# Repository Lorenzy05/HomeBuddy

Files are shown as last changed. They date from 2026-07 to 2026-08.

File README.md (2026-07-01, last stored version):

# 🏠 HomeBuddy - Home Service Robot · Ultimate Project Plan

> **Version**: v1.2
> **Date**: 2026-07-01
> **Updates**: Procurement via purchase or 3D printing; simplified power architecture; removed mobile App control; restructured implementation into task modules.

---

## 📖 Table of Contents

1. [Project Overview](#1-project-overview)
2. [System Architecture](#2-system-architecture)
3. [Hardware List](#3-hardware-list)
4. [Wiring Scheme](#4-wiring-scheme)
5. [Communication Protocol](#5-communication-protocol)
6. [Control Methods](#6-control-methods)
7. [Function Modules](#7-function-modules)
8. [Implementation Tasks](#8-implementation-tasks)
9. [Acceptance Criteria](#9-acceptance-criteria)
10. [Risks & Mitigations](#10-risks--mitigations)
11. [Future Extensions](#11-future-extensions)

## 1. Project Overview

| Item | Description |
|---|---|
| 🏠 Project Name | **HomeBuddy** |
| 🎯 Positioning | Home intelligent service robot |
| ✨ Core Functions | 🗣️ Voice Chat · 👁️ Face Following · 🎮 Remote Control · 📦 Auto Delivery |
| 🧠 Architecture | Raspberry Pi (Brain) + ESP32-S3 (Executor) |
| 🎛️ Control Methods | Voice 🎤 + Remote 📟 (Dual Mode) |

### 🧭 Design Principles

| Principle | Description |
|---|---|
| 🔹 Separation of Concerns | Raspberry Pi handles AI, ESP32 handles hardware |
| 🔹 Wired Communication | UART serial, stable and reliable |
| 🔹 Dual Control | Voice + Remote, switch anytime |
| 🔹 Safety First | Remote can take over anytime for emergency stop |
| 🔹 Plug & Play | All audio devices are USB, no extra drivers needed |

## 2. System Architecture

```
┌─────────────────────────────────────────────────────────────────┐
│                      👤 User Interaction Layer                  │
│  ┌─────────────────────┐  ┌─────────────────────┐            │
│  │      🎤 Voice       │  │     📟 Remote       │            │
│  │     Control         │  │     Control         │            │
│  │  (Natural Language) │  │  (IR Physical Keys) │            │
│  └──────────┬──────────┘  └──────────┬──────────┘            │
│             └────────────┬────────────┘                       │
└──────────────────────────┼────────────────────────────────────┘
                           │
┌──────────────────────────┼────────────────────────────────────┐
│                          ▼                                     │
│              🧠 Raspberry Pi 4B (Brain / 8GB)                 │
│  ┌────────────────────────────────────────────────────────┐   │
│  │  📦 Software Functions:                               │   │
│  │  🎤 Vosk STT (Speech Recognition)                    │   │
│  │  🔊 Edge-TTS (Speech Synthesis)                      │   │
│  │  🤖 Ollama (Local LLM / Gemma 2B)                   │   │
│  │  👁️ MediaPipe (Face Detection)                       │   │
│  │  🎯 Face Following Algorithm (PID Control)           │   │
│  │  🔄 Mode Management (Remote / Follow / Delivery)     │   │
│  └──────────────────┬─────────────────────────────────────┘   │
│                     │ 🔗 UART Serial (GPIO14/15)               │
│                     │ 📨 Command Protocol                     │
│                     │ 🔋 Power: Power Bank (USB-C)            │
└─────────────────────┼────────────────────────────────────────┘
                      │
┌─────────────────────┼────────────────────────────────────────┐
│                     ▼                                         │
│            ⚙️ ESP32-S3 (Executor / Sub-brain)                 │
│  ┌────────────────────────────────────────────────────────┐   │
│  │  🔧 Hardware Control:                                 │   │
│  │  🚗 L298N → DC Motors ×2 (Wheels)                    │   │
│  │  🦾 SG90 Servos ×3-4 (Pan-Tilt / Tray / Head)        │   │
│  │  🧭 MPU6050 (IMU / Anti-spill Compensation)          │   │
│  │  📟 HX1838 (IR Remote Receiver)                      │   │
│  │  🖥️ OLED SSD1306 (Face/Expression Display)           │   │
│  │  💡 NeoPixel (RGB Status LED)                        │   │
│  │  🔋 ADC (Battery Monitoring)                         │   │
│  └────────────────────────────────────────────────────────┘   │
└─────────────────────────────────────────────────────────────────┘
```

### 🎵 Audio Solution

```
┌─────────────────────────────────────────────────────┐
│           Raspberry Pi USB Audio Solution           │
│  ┌───────────────┐    ┌───────────────┐           │
│  │  🎤 STJF USB  │    │  🔊 Dual      │           │
│  │  Microphone   │    │  USB Speaker  │           │
│  │  (Audio In)   │    │  (Audio Out)  │           │
│  └───────┬───────┘    └───────┬───────┘           │
│          │                    │                    │
│          └────────┬───────────┘                    │
│                   ▼                                │
│          ┌─────────────────┐                       │
│          │  Raspberry Pi   │                       │
│          │  USB Ports      │                       │
│          │  (Plug & Play)  │                       │
│          └─────────────────┘                       │
└─────────────────────────────────────────────────────┘
```

## 3. Hardware List

### ✅ Already Owned

| Component | Model | Qty | Status |
|---|---|:---:|:---:|
| 🧠 Main Board 1 | Raspberry Pi 4B 8GB + 128GB | 1 | ✅ Owned |
| ⚙️ Main Board 2 | ESP32-S3 DevKit | 1 | ✅ Owned |
| 📷 Camera | USB Webcam 1080P | 1 | ✅ Owned |
| 🎤 Microphone | STJF mini USB Microphone | 1 | ✅ Owned |
| 🔊 Speaker | Dual Horn USB Speaker | 1 | ✅ Owned |
| 🔋 Power Bank | Power Bank (USB-C Output) | 1 | ✅ Owned |
| 🦾 Servo | SG90 9g | 3-4 | ✅ Owned |
| 🧭 IMU | MPU6050 | 1 | ✅ Owned |
| 🚗 Motor Driver | L298N | 1 | ✅ Owned |
| 🖥️ Display | OLED SSD1306 128x64 | 1 | ✅ Owned |
| 💡 RGB LED | NeoPixel | 1 | ✅ Owned |
| 📟 IR Receiver | HX1838 + Remote Control | 1 | ✅ Owned |
| 🎤 Mic (spare) | INMP441 | 1 | ⚠️ Spare |
| 🔊 Amp (spare) | MAX98357A | 1 | ⚠️ Spare |

### 🆕 To Purchase (Buy or 3D Print)

| # | Item | Spec | Qty | Budget | Notes |
|:-:|---|---|:---:|:---:|---|
| 1 | 🛞 Chassis | 30×25cm Acrylic / 3D Printed | 1 | ¥20-40 | Buy or self-print |
| 2 | 🏎️ Rubber Wheels | Diameter 8-10cm | 2 | ¥60-100 | Purchase |
| 3 | 🔄 Caster Wheel | Metal bracket | 1 | ¥15-20 | Purchase |
| 4 | 🔋 LiPo Battery | 12V 3S 18650 (with protection) | 1 | ¥120-180 | Only for L298N + motors |
| 5 | 🔩 Standoff + Screw Kit | M2.5/M3 various lengths | 1 set | ¥20-30 | Purchase |
| 6 | 📡 Jumper Wire Set | M/M, M/F, F/F | 1 set | ¥15 | Purchase |
| 7 | 🔌 USB Extension Cable | Male to Female, 1m | 1 | ¥10 | Flexible camera placement |
| 8 | 🎗️ Cable Ties + Nano Tape | Assorted | 1 pack | ¥10 | Purchase |
| 9 | 🖨️ 3D Printing Filament | PLA / PETG (if self-printing) | 1 spool | ¥60-100 | Optional |

**Total Budget: ~¥330-555**

## 4. Wiring Scheme

### 4.1 🌲 Raspberry Pi Side

| Port | → Connected To | Description |
|---|---|---|
| USB-A | 📷 USB Webcam | Video Input |
| USB-A | 🎤 STJF USB Microphone | Audio Input (Speech Recognition) |
| USB-A | 🔊 Dual USB Speaker | Audio Output (TTS) |
| USB-C | 🔋 Power Bank | Raspberry Pi Power |
| GPIO14 (TX) | ⚙️ ESP32 RX | Serial TX |
| GPIO15 (RX) | ⚙️ ESP32 TX | Serial RX |
| GND | ⚙️ ESP32 GND | Common Ground |

### 4.2 ⚙️ ESP32 Side

| Pin | → Connected To | Description |
|-----|---|---|
| UART RX | 🌲 Raspberry Pi TX | Receive Commands |
| UART TX | 🌲 Raspberry Pi RX | Send Feedback |
| GND | 🌲 Raspberry Pi GND | Common Ground |
| GPIO4 | 🚗 L298N IN1 | Left Motor A |
| GPIO5 | 🚗 L298N IN2 | Left Motor B |
| GPIO6 | 🚗 L298N IN3 | Right Motor A |
| GPIO7 | 🚗 L298N IN4 | Right Motor B |
| GPIO8 (PWM) | 🦾 SG90 Servo 1 | Pan (Left/Right) |
| GPIO9 (PWM) | 🦾 SG90 Servo 2 | Tilt (Up/Down) |
| GPIO10 (PWM) | 🦾 SG90 Servo 3 | Tray Compensation |
| GPIO13 | 📟 HX1838 OUT | IR Receiver |
| GPIO21 (SDA) | 🧭 MPU6050 SDA | I2C Data |
| GPIO22 (SCL) | 🧭 MPU6050 SCL | I2C Clock |
| GPIO21 (SDA) | 🖥️ OLED SDA | Parallel with MPU6050 |
| GPIO22 (SCL) | 🖥️ OLED SCL | Parallel with MPU6050 |
| GPIO48 | 💡 NeoPixel DATA | RGB Status LED |
| GPIO32 (ADC) | 🔋 Battery Voltage Divider | Battery Monitoring |
| VIN (5V) | 🔋 Power Bank (USB-A or USB-C) | ESP32 Power |

### 4.3 🔋 Power System

```
🔋 Power Bank
    ├── USB-C → 🌲 Raspberry Pi (5V)
    └── USB-A → ⚙️ ESP32-S3 (5V)

🔋 12V LiPo Battery Pack (3S 18650, Independent)
    └── 🚗 Direct → L298N (Motor Driver, 12V Input)
```

**Power Distribution**:

| Power Source | Powers | Description |
|---|---|---|
| 🔋 Power Bank | 🌲 Raspberry Pi + USB Peripherals + ⚙️ ESP32 | 5V output, stable |
| 🔋 12V LiPo Pack | 🚗 L298N + Motors | Independent, high current doesn't干扰 control circuit |

> ✅ **Advantage**: Raspberry Pi + ESP32 power is completely isolated from motors, preventing voltage drops during motor startup that could cause resets.

## 5. Communication Protocol

### 5.1 🌲 Raspberry Pi → ⚙️ ESP32 (Commands)

| Command Format | Parameters | Function |
|---|---|---|
| `!MOTOR#L{left}#R{right}#END` | -100 ~ 100 | 🚗 Differential drive control |
| `!PAN#{angle}#END` | -90 ~ 90 | 🔄 Pan servo control |
| `!TILT#{angle}#END` | -45 ~ 45 | 🔄 Tilt servo control |
| `!TRAY#{angle}#END` | -15 ~ 15 | 📦 Tray tilt compensation |
| `!EMOJI#{ID}#END` | 0=😊 1=🎯 2=😢 3=🤖 | 🖥️ Expression switch |
| `!RGB#R{red}#G{green}#B{blue}#END` | 0~255 | 💡 RGB LED color |
| `!MODE#{mode}#END` | 0=Remote 1=Follow 2=Delivery | 🔄 Mode switch |
| `!STOP#END` | — | 🛑 Emergency stop |

### 5.2 ⚙️ ESP32 → 🌲 Raspberry Pi (Feedback)

| Feedback Format | Frequency | Function |
|---|:---:|---|
| `!IMU#ROLL{angle}#PITCH{angle}#END` | 10Hz | 🧭 IMU data |
| `!BATTERY#{voltage}#END` | 1Hz | 🔋 Motor battery voltage |
| `!IR#{key_code}#END` | Event | 📟 Remote key press |

## 6. Control Methods

### 🎛️ Dual Control Modes

| Mode | Trigger | Description |
|---|---|---|
| 🎮 **Remote Mode** | IR Remote | Manual control of movement and pan-tilt |
| 👁️ **Follow Mode** | Voice / Remote toggle | Automatic face following |
| 📦 **Delivery Mode** | Voice "bring me water" | Auto find person + deliver |

### 📟 IR Remote Key Mapping (17-key Standard)

| Key | Function | Priority |
|-----|---|:---:|
| **Direction Pad** | | |
| ↑ | 🚗 Forward | ⭐⭐⭐ |
| ↓ | 🚗 Backward | ⭐⭐⭐ |
| ← | 🔄 Turn Left | ⭐⭐⭐ |
| → | 🔄 Turn Right | ⭐⭐⭐ |
| **Control Pad** | | |
| OK | 🛑 Emergency Stop | ⭐⭐⭐ |
| 0 | 🔄 Mode Switch (Remote ↔ Follow ↔ Delivery) | ⭐⭐ |
| 1 | 🎯 Pan-Tilt Center | ⭐⭐ |
| 2 | 🔄 Pan Left 15° | ⭐⭐ |
| 3 | 🔄 Pan Right 15° | ⭐⭐ |
| 4 | 🔄 Tilt Up 15° | ⭐⭐ |
| 5 | 🔄 Tilt Down 15° | ⭐⭐ |
| **Shortcuts** | | |
| 6 | 📦 Delivery Command | ⭐⭐ |
| 7 | 👋 Say Hello (TTS) | ⭐ |
| 8 | 👁️ Start Face Following | ⭐⭐ |
| 9 | 🏠 Return to Charging Station (Reserved) | ⭐ |
| \* | ⏩ Increase Speed | ⭐ |
| \# | ⏪ Decrease Speed | ⭐ |

### ⚡ Control Priority

```
🥇 Highest: Remote Direction Keys + OK (always active)
🥈 Medium: Remote Function Keys
🥉 Normal: Voice Commands + Auto Following
```

> 🔒 **Safety Mechanism**: Pressing a direction key → pauses all auto modes → manual takeover

## 7. Function Modules

| Module | Chip | Function | Priority |
|---|---|---|:---:|
| 🎤 Speech Recognition | RPi | STJF USB Mic → Vosk STT | 🔴 P0 |
| 🔊 Speech Synthesis | RPi | Edge-TTS → Dual USB Speaker | 🔴 P0 |
| 🤖 Smart Chat | RPi | Ollama (Gemma 2B) | 🔴 P0 |
| 👁️ Face Detection | RPi | MediaPipe + USB Webcam | 🔴 P0 |
| 🎯 Face Following | RPi | PID Control + Speed Mapping | 🔴 P0 |
| 📟 IR Remote | ESP32 | HX1838 Signal Decoding | 🔴 P0 |
| 🚗 Motor Control | ESP32 | L298N PWM Speed Control | 🔴 P0 |
| 🦾 Servo Pan-Tilt | ESP32 | SG90 Angle Control | 🔴 P0 |
| 🔄 Mode Management | RPi | 3-mode switching logic | 🟡 P1 |
| 🧭 IMU Sensing | ESP32 | MPU6050 Reading | 🟡 P1 |
| 📦 Anti-spill | ESP32 | IMU → Servo Compensation | 🟡 P1 |
| 🖥️ Expression Display | ESP32 | OLED Dynamic Faces | 🟡 P1 |
| 💡 Status LED | ESP32 | NeoPixel RGB | 🟡 P1 |
| 🔋 Battery Monitor | ESP32 | ADC Voltage Sampling | 🟢 P2 |

**Priority Legend**:
- 🔴 P0 = Core functions, must implement
- 🟡 P1 = Important, improves experience
- 🟢 P2 = Nice-to-have, future iteration

## 8. Implementation Tasks

### 🔧 Hardware Build Tasks

| # | Task | Description |
|:-:|---|---|
| 1 | 🛞 Chassis Fabrication | Buy acrylic or 3D print chassis, size 30×25cm |
| 2 | 🔩 Motor Installation | Mount L298N + DC motors + wheels to chassis |
| 3 | 🧱 Layer Stacking | Use standoffs: Bottom = battery+L298N, Middle = ESP32, Top = Raspberry Pi |
| 4 | 📷 Camera Mount | Mount USB Webcam on servo pan-tilt |
| 5 | 🔌 Wiring | Connect all hardware per wiring scheme |
| 6 | 🔋 Power Test | Verify Power Bank powers Pi/ESP32, LiPo powers L298N |
| 7 | 📟 IR Decoding | Flash IRrecv example, read each remote key's code |

### 💻 Software Development Tasks (In Order)

| # | Module | Description |
|:-:|---|---|
| 1 | ⚙️ ESP32 Serial | Implement `!MOTOR` / `!PAN` / `!TILT` command parsing |
| 2 | ⚙️ ESP32 Motor Test | Manual commands to verify L298N forward/reverse |
| 3 | ⚙️ ESP32 Servo Test | Manual commands to verify SG90 angle control |
| 4 | ⚙️ ESP32 IR Decode | Map remote keys to actions |
| 5 | ⚙️ ESP32 MPU6050 | Read IMU data and send via serial to Raspberry Pi |
| 6 | ⚙️ ESP32 OLED + NeoPixel | Expression switching + status LED effects |
| 7 | 🌲 RPi USB Audio | Test recording (mic) and playback (speaker) |
| 8 | 🌲 RPi Vosk STT | Offline speech recognition |
| 9 | 🌲 RPi Edge-TTS | Text-to-speech via speaker |
| 10 | 🌲 RPi MediaPipe | USB Webcam face detection (draw bounding box) |
| 11 | 🌲 RPi Face Following | Calculate face offset → PID → send `!MOTOR` to ESP32 |
| 12 | 🌲 RPi Ollama | Integrate local LLM chat capability |
| 13 | 🔄 Mode Manager | Implement Remote / Follow / Delivery 3-mode switching |
| 14 | 🧪 Full System Test | Voice trigger → Face follow → Delivery → TTS response |

### 🧪 Testing & Debugging Tasks

| # | Task | Description |
|:-:|---|---|
| 1 | 🚗 Remote Movement Test | Control forward/backward/turn with remote, check response speed |
| 2 | 🎯 Face Following Test | Person moves, robot follows automatically |
| 3 | 🗣️ Voice Interaction Test | Say "hello" → recognition → LLM reply → TTS |
| 4 | 📦 Delivery Scenario Test | Say "bring me water" → find person → deliver → voice alert |
| 5 | 🧊 Anti-spill Test | Emergency stop, observe tray stays level |
| 6 | 🔋 Battery Life Test | Continuous run, record runtime |
| 7 | 📟 IR Interference Test | Test remote in bright light, at various angles |
| 8 | 🎤 Audio Noise Test | Voice recognition with motors running |

## 9. Acceptance Criteria

### ✅ Functional Acceptance

| Function | Acceptance Criteria | Status |
|---|---|:---:|
| 🎮 Remote Movement | Direction keys control smooth movement | ⬜ Pending |
| 🔄 Pan-Tilt Control | Camera rotates smoothly | ⬜ Pending |
| 👁️ Face Detection | Face box drawn on screen with coordinates | ⬜ Pending |
| 🎯 Face Following | Robot follows person moving around room | ⬜ Pending |
| 🎤 Speech Recognition | STJF mic accurately recognizes Chinese commands | ⬜ Pending |
| 🔊 Speech Synthesis | Dual speaker plays TTS clearly | ⬜ Pending |
| 📦 Auto Delivery | "Bring water" → find person → deliver | ⬜ Pending |
| 📟 IR Remote | All keys function correctly | ⬜ Pending |
| 🧊 Anti-spill | Tray compensation effective during sudden stops | ⬜ Pending |
| 🖥️ Expression Display | OLED switches between expressions | ⬜ Pending |
| 💡 Status LED | RGB shows different colors for different states | ⬜ Pending |
| 🔄 Mode Switching | Remote/Follow/Delivery switch smoothly | ⬜ Pending |
| 🔋 Dual Power | Power Bank + LiPo work stable together | ⬜ Pending |

### 📊 Performance Acceptance

| Metric | Requirement | Notes |
|---|---|---|
| 🔋 Battery Life | ≥ 2 hours (continuous movement) | Depends on LiPo capacity |
| 🔋 Pi Power | Power Bank independent | No motor interference |
| 📦 Max Payload | ≥ 500g | 1 bottle of water + snacks |
| 🏎️ Max Speed | 0.5 m/s | Safe indoor speed |
| ⏱️ Following Latency | < 200ms | Should not feel laggy |
| 🎤 Speech Recognition | > 80% accuracy | In quiet environment |
| 📟 Remote Range | ≥ 8 meters | Sufficient indoors |
| 🔊 Speaker Volume | Clearly audible at 5 meters | Dual speaker advantage |

## 10. Risks & Mitigations

| ⚠️ Risk | 📌 Impact | 🛠️ Mitigation |
|---|---|---|
| 🔋 Power Bank insufficient output | Pi throttles/reboots | Use Power Bank that supports 5V/3A output |
| 🔋 Motor startup voltage drop | ESP32 resets | Isolate Pi/ESP32 power from motors |
| 🎤 USB Mic latency | Voice interaction lag | Lower sample rate / ALSA low-latency config |
| 🔊 USB Speaker no sound | TTS fails | Check ALSA default output device |
| 📡 Not enough USB ports | Can't plug all devices | Pi 4B has 4 USB ports, enough; or use USB HUB |
| 💧 Spilled drink | Core function fails | Ramp up/down speed + MPU6050 hardware compensation |
| 🌀 Face following jitter | Poor experience | Tune PID parameters, reduce sensitivity |
| ☀️ IR interference from strong light | Remote fails | Avoid direct sunlight on receiver |

## 11. Future Extensions

| Feature | Hardware Needed | Priority |
|---|---|:---:|
| 🚧 Obstacle Avoidance | HC-SR04 Ultrasonic Sensor | ⭐⭐⭐ |
| 🗺️ Mapping & Navigation | RPLIDAR Laser Scanner | ⭐⭐ |
| 🔋 Auto Recharging | Charging Dock + IR Guidance | ⭐⭐ |
| 📹 Remote Monitoring | Camera streaming (already have) | ⭐⭐⭐ |
| ✋ Gesture Recognition | Existing Camera | ⭐⭐ |
| 📦 Object Recognition | Existing Camera + YOLO | ⭐⭐ |
| 🌍 Multi-language Support | Change Vosk model | ⭐ |

## 📌 Appendices

### A. Audio Device Configuration Notes

| Device | Configuration Method |
|---|---|
| 🎤 STJF USB Microphone | `arecord -l` to find device, specify `device` in Vosk |
| 🔊 Dual USB Speaker | `aplay -l` to find device, specify in Pygame |
| 🎵 Volume Control | Use `alsamixer` to adjust USB speaker volume |

**Raspberry Pi USB Audio Test Commands**:
```bash
# Test recording (STJF Mic)
arecord -D plughw:1,0 -d 5 -f S16_LE -r 16000 test.wav

# Test playback (Dual Speaker)
aplay -D plughw:2,0 test.wav
```

### B. Reference Resources

| Resource | Link / Description |
|---|---|
| Vosk Chinese Model | https://alphacephei.com/vosk/models |
| Ollama | https://ollama.ai |
| MediaPipe | https://mediapipe.dev |
| IRremote Library | Search "IRremote" in Arduino Library Manager |
| ALSA Configuration | `/etc/asound.conf` to set default sound card |

### C. Document Version History

| Version | Date | Changes |
|---|---|---|
| v1.0 | 2026-07-01 | Initial release |
| v1.1 | 2026-07-01 | Integrated STJF USB mic + Dual USB speaker + Power Bank |
| v1.2 | 2026-07-01 | Procurement via buy/3D print; removed mobile App; simplified power; restructured tasks |

---

**🏠 HomeBuddy · Smarter Home, Warmer Life ❤️**

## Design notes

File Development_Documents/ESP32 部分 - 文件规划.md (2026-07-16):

## ⚙️ ESP32 部分 - 文件规划

### 📊 总览：需要 8 个文件

| # | 文件名 | 核心功能 | 行数估算 |
|:-:|---|---|:---:|
| 1 | `main.cpp` | 程序入口，初始化硬件，主循环调度 | ~80 |
| 2 | `protocol.h` | 串口指令解析器（字符串 → 结构体） | ~80 |
| 3 | `motor_control.cpp` | L298N 驱动，PWM 调速 | ~60 |
| 4 | `servo_control.cpp` | SG90 舵机控制（PAN/TILT/TRAY） | ~50 |
| 5 | `ir_receiver.cpp` | HX1838 红外遥控解码 | ~70 |
| 6 | `imu_sensor.cpp` | MPU6050 姿态读取（I2C） | ~60 |
| 7 | `led_display.cpp` | OLED 表情 + NeoPixel 灯效 | ~70 |
| 8 | `priority_manager.cpp` | 控制优先级管理（遥控强制接管） | ~50 |
| **合计** | | | **~520 行** |

---

## 📁 每个文件的详细说明

### 1. `main.cpp` — 程序入口 & 主循环

**功能**：
- 初始化所有硬件（串口、GPIO、I2C、PWM）
- 主循环 `loop()` 调度所有模块
- 每 100ms 发送 IMU 数据给树莓派
- 每 500ms 发送电池电量
- 实时响应串口指令和遥控器按键
- 看门狗保护（防止卡死）

**伪代码**：
```cpp
#include "protocol.h"
#include "motor_control.h"
#include "servo_control.h"
#include "ir_receiver.h"
#include "imu_sensor.h"
#include "led_display.h"
#include "priority_manager.h"

void setup() {
    Serial.begin(115200);
    initMotor();
    initServo();
    initIR();
    initIMU();
    initLED();
    initPriorityManager();
    Serial.println("HomeBuddy ESP32 Ready");
}

void loop() {
    // 1. 处理串口指令（来自树莓派）
    if (Serial.available()) {
        String cmd = Serial.readStringUntil('\n');
        parseCommand(cmd);  // 在 protocol.h 中实现
    }
    
    // 2. 处理遥控器按键（最高优先级）
    int irKey = readIR();
    if (irKey != 0) {
        handleRemoteKey(irKey);  // 在 ir_receiver.cpp 中实现
    }
    
    // 3. 每 100ms 发送 IMU 数据
    static unsigned long lastIMU = 0;
    if (millis() - lastIMU > 100) {
        float roll = getRoll();
        float pitch = getPitch();
        Serial.printf("!IMU#ROLL%.2f#PITCH%.2f#END\n", roll, pitch);
        lastIMU = millis();
    }
    
    // 4. 每 500ms 发送电池电量
    static unsigned long lastBAT = 0;
    if (millis() - lastBAT > 500) {
        float voltage = readBattery();
        Serial.printf("!BATTERY#%.2f#END\n", voltage);
        lastBAT = millis();
    }
    
    // 5. 更新 LED 表情 + 灯效（非阻塞）
    updateLEDs();
}
```

---

### 2. `protocol.h` — 串口协议解析器

**功能**：
- 定义所有指令格式（`!MOTOR`、`!PAN`、`!EMOJI` 等）
- 解析字符串指令 → 提取参数
- 调用对应的控制函数
- 非法指令处理（返回 `!ERR`）

**示例**：
```cpp
// protocol.h
#ifndef PROTOCOL_H
#define PROTOCOL_H

#include "motor_control.h"
#include "servo_control.h"
#include "led_display.h"

void parseCommand(String cmd) {
    if (cmd.startsWith("!MOTOR#")) {
        int left = getValue(cmd, 'L');
        int right = getValue(cmd, 'R');
        setMotorSpeed(left, right);
    }
    else if (cmd.startsWith("!PAN#")) {
        int angle = getValue(cmd, 'P');
        setPan(angle);
    }
    else if (cmd.startsWith("!TILT#")) {
        int angle = getValue(cmd, 'T');
        setTilt(angle);
    }
    else if (cmd.startsWith("!TRAY#")) {
        int angle = getValue(cmd, 'Y');
        setTray(angle);
    }
    else if (cmd.startsWith("!EMOJI#")) {
        int id = getValue(cmd, 'E');
        showEmoji(id);
    }
    else if (cmd.startsWith("!RGB#")) {
        int r = getValue(cmd, 'R');
        int g = getValue(cmd, 'G');
        int b = getValue(cmd, 'B');
        setRGB(r, g, b);
    }
    else if (cmd.startsWith("!STOP#")) {
        setMotorSpeed(0, 0);
    }
    else {
        Serial.println("!ERR#UNKNOWN#END");
    }
}

// 工具函数：从字符串中提取指定键的值
// 例：!MOTOR#L50#R60#END → getValue(cmd, 'L') 返回 50
int getValue(String cmd, char key) {
    int start = cmd.indexOf(key) + 1;
    int end = cmd.indexOf('#', start);
    return cmd.substring(start, end).toInt();
}

#endif
```

---

### 3. `motor_control.cpp` — L298N 电机控制

**功能**：
- 初始化 L298N 的 4 个 GPIO（IN1~IN4）
- 接收左右速度值（-100 ~ 100）
- 正转/反转/停止
- 梯形加减速（防止急刹洒水）

**引脚分配**：
```
L298N IN1 → GPIO4
L298N IN2 → GPIO5
L298N IN3 → GPIO6
L298N IN4 → GPIO7
```

**示例**：
```cpp
// motor_control.cpp
#include "motor_control.h"
#include <Arduino.h>

#define IN1 4
#define IN2 5
#define IN3 6
#define IN4 7

void initMotor() {
    pinMode(IN1, OUTPUT);
    pinMode(IN2, OUTPUT);
    pinMode(IN3, OUTPUT);
    pinMode(IN4, OUTPUT);
    setMotorSpeed(0, 0);
}

void setMotorSpeed(int left, int right) {
    // 限制速度范围
    left = constrain(left, -100, 100);
    right = constrain(right, -100, 100);
    
    // 左电机
    if (left > 0) {
        analogWrite(IN1, left * 2.55);
        digitalWrite(IN2, LOW);
    } else if (left < 0) {
        digitalWrite(IN1, LOW);
        analogWrite(IN2, -left * 2.55);
    } else {
        digitalWrite(IN1, LOW);
        digitalWrite(IN2, LOW);
    }
    
    // 右电机
    if (right > 0) {
        analogWrite(IN3, right * 2.55);
        digitalWrite(IN4, LOW);
    } else if (right < 0) {
        digitalWrite(IN3, LOW);
        analogWrite(IN4, -right * 2.55);
    } else {
        digitalWrite(IN3, LOW);
        digitalWrite(IN4, LOW);
    }
}
```

---

### 4. `servo_control.cpp` — SG90 舵机控制

**功能**：
- 初始化 3 个舵机（PAN / TILT / TRAY）
- PAN：-90° ~ 90°（左右旋转）
- TILT：-45° ~ 45°（上下俯仰）
- TRAY：-15° ~ 15°（托盘倾斜补偿）
- 平滑移动（防止抖动）

**引脚分配**：
```
PAN  → GPIO8
TILT → GPIO9
TRAY → GPIO10
```

**示例**：
```cpp
// servo_control.cpp
#include "servo_control.h"
#include <Servo.h>

Servo panServo, tiltServo, trayServo;

void initServo() {
    panServo.attach(8);
    tiltServo.attach(9);
    trayServo.attach(10);
    setPan(0);
    setTilt(0);
    setTray(0);
}

void setPan(int angle) {
    angle = constrain(angle, -90, 90);
    panServo.write(angle + 90);  // 0° → 90, -90° → 0, 90° → 180
}

void setTilt(int angle) {
    angle = constrain(angle, -45, 45);
    tiltServo.write(angle + 90);
}

void setTray(int angle) {
    angle = constrain(angle, -15, 15);
    trayServo.write(angle + 90);
}

void centerServos() {
    setPan(0);
    setTilt(0);
    setTray(0);
}
```

---

### 5. `ir_receiver.cpp` — HX1838 红外遥控解码

**功能**：
- 初始化 HX1838 红外接收头
- 读取遥控器按键编码
- 按键 → 功能映射表
- 方向键强制接管（最高优先级）
- 按键防抖处理

**引脚分配**：
```
HX1838 OUT → GPIO13
```

**示例**：
```cpp
// ir_receiver.cpp
#include "ir_receiver.h"
#include <IRremote.h>

#define IR_PIN 13

IRrecv irrecv(IR_PIN);
decode_results results;

// 按键映射表（需要先解码你的遥控器）
#define KEY_UP    0xFFA25D
#define KEY_DOWN  0xFF629D
#define KEY_LEFT  0xFF22DD
#define KEY_RIGHT 0xFF02FD
#define KEY_OK    0xFFA857
#define KEY_0     0xFF6897
#define KEY_1     0xFF30CF
#define KEY_2     0xFF18E7
#define KEY_3     0xFF7A85
#define KEY_4     0xFF10EF
#define KEY_5     0xFF38C7
#define KEY_6     0xFF5AA5
#define KEY_7     0xFF42BD
#define KEY_8     0xFF4AB5
#define KEY_9     0xFF52AD
#define KEY_STAR  0xFFA857  // 你的 * 键编码
#define KEY_HASH  0xFFB04F  // 你的 # 键编码

void initIR() {
    irrecv.enableIRIn();
}

int readIR() {
    if (irrecv.decode(&results)) {
        unsigned long value = results.value;
        irrecv.resume();  // 继续接收
        return value;
    }
    return 0;
}

void handleRemoteKey(unsigned long key) {
    switch (key) {
        case KEY_UP:    handlePriorityAction(MOVE_FORWARD); break;
        case KEY_DOWN:  handlePriorityAction(MOVE_BACKWARD); break;
        case KEY_LEFT:  handlePriorityAction(MOVE_LEFT); break;
        case KEY_RIGHT: handlePriorityAction(MOVE_RIGHT); break;
        case KEY_OK:    handlePriorityAction(STOP); break;
        case KEY_0:     handlePriorityAction(MODE_SWITCH); break;
        case KEY_1:     setPan(0); setTilt(0); break;
        case KEY_2:     setPan(-15); break;
        case KEY_3:     setPan(15); break;
        case KEY_4:     setTilt(-10); break;
        case KEY_5:     setTilt(10); break;
        case KEY_6:     Serial.println("!IR#DELIVERY#END"); break;
        case KEY_8:     Serial.println("!IR#FOLLOW#END"); break;
        case KEY_STAR:  increaseSpeed(); break;
        case KEY_HASH:  decreaseSpeed(); break;
        default: break;
    }
}
```

---

### 6. `imu_sensor.cpp` — MPU6050 姿态读取

**功能**：
- 初始化 MPU6050（I2C）
- 读取 Roll（左右倾斜）和 Pitch（前后倾斜）
- 提供给主循环发送 `!IMU` 数据
- 用于防洒补偿

**引脚分配**：
```
MPU6050 SDA → GPIO21
MPU6050 SCL → GPIO22
```

**示例**：
```cpp
// imu_sensor.cpp
#include "imu_sensor.h"
#include <Wire.h>
#include <MPU6050.h>

MPU6050 mpu;

void initIMU() {
    Wire.begin(21, 22);
    mpu.initialize();
}

float getRoll() {
    // 简化版：直接从 MPU6050 读取
    // 实际需要校准和滤波
    int16_t ax, ay, az;
    mpu.getAcceleration(&ax, &ay, &az);
    return atan2(ay, az) * 180.0 / PI;
}

float getPitch() {
    int16_t ax, ay, az;
    mpu.getAcceleration(&ax, &ay, &az);
    return atan2(-ax, sqrt(ay*ay + az*az)) * 180.0 / PI;
}
```

---

### 7. `led_display.cpp` — OLED 表情 + NeoPixel 灯效

**功能**：
- OLED SSD1306 显示表情（😊 🎯 😢 🤖）
- NeoPixel RGB 状态指示灯
- 接收 `!EMOJI` 和 `!RGB` 指令

**引脚分配**：
```
OLED SDA → GPIO21（与 MPU6050 并联）
OLED SCL → GPIO22（与 MPU6050 并联）
NeoPixel DATA → GPIO48
```

**示例**：
```cpp
// led_display.cpp
#include "led_display.h"
#include <Adafruit_SSD1306.h>
#include <Adafruit_NeoPixel.h>

#define OLED_WIDTH 128
#define OLED_HEIGHT 64
#define OLED_ADDR 0x3C
#define NEOPIXEL_PIN 48

Adafruit_SSD1306 oled(OLED_WIDTH, OLED_HEIGHT, &Wire, -1);
Adafruit_NeoPixel rgb(1, NEOPIXEL_PIN, NEO_GRB + NEO_KHZ800);

void initLED() {
    oled.begin(SSD1306_SWITCHCAPVCC, OLED_ADDR);
    oled.clearDisplay();
    oled.display();
    
    rgb.begin();
    rgb.show();
}

void showEmoji(int id) {
    oled.clearDisplay();
    oled.setTextSize(3);
    oled.setTextColor(SSD1306_WHITE);
    oled.setCursor(30, 20);
    
    switch (id) {
        case 0: oled.print("😊"); break;  // 开心
        case 1: oled.print("🎯"); break;  // 锁定目标
        case 2: oled.print("😢"); break;  // 丢失
        case 3: oled.print("🤖"); break;  // 思考中
        default: oled.print("🤖"); break;
    }
    oled.display();
}

void setRGB(int r, int g, int b) {
    rgb.setPixelColor(0, rgb.Color(r, g, b));
    rgb.show();
}
```

---

### 8. `priority_manager.cpp` — 控制优先级管理

**功能**：
- 管理控制优先级：**遥控器 > 树莓派串口指令**
- 当遥控器方向键被按下时，强制接管控制权
- 停止当前所有自动动作
- 方向键松开后，可恢复之前模式

**示例**：
```cpp
// priority_manager.cpp
#include "priority_manager.h"
#include "motor_control.h"

enum PriorityMode {
    PRIORITY_REMOTE,
    PRIORITY_SERIAL
};

PriorityMode currentPriority = PRIORITY_SERIAL;

void initPriorityManager() {
    currentPriority = PRIORITY_SERIAL;
}

void handlePriorityAction(int action) {
    // 任何遥控器动作都强制切换到远程优先级
    currentPriority = PRIORITY_REMOTE;
    
    switch (action) {
        case MOVE_FORWARD: setMotorSpeed(60, 60); break;
        case MOVE_BACKWARD: setMotorSpeed(-60, -60); break;
        case MOVE_LEFT: setMotorSpeed(-50, 50); break;
        case MOVE_RIGHT: setMotorSpeed(50, -50); break;
        case STOP: setMotorSpeed(0, 0); break;
        default: break;
    }
}

void releaseRemoteControl() {
    // 在模式切换时调用，恢复串口控制
    currentPriority = PRIORITY_SERIAL;
}

bool isRemoteInControl() {
    return currentPriority == PRIORITY_REMOTE;
}
```

---

## 📊 文件依赖关系

```
main.cpp
  ├── protocol.h（指令解析）
  │   ├── motor_control.cpp（L298N 驱动）
  │   ├── servo_control.cpp（SG90 舵机）
  │   └── led_display.cpp（OLED + NeoPixel）
  ├── ir_receiver.cpp（HX1838 遥控）
  │   └── priority_manager.cpp（优先级管理）
  │       └── motor_control.cpp
  └── imu_sensor.cpp（MPU6050）
```

---

## ✅ 总结

| 类别 | 文件数量 | 说明 |
|---|:---:|---|
| 主程序 | 1 | `main.cpp` |
| 协议解析 | 1 | `protocol.h` |
| 硬件驱动 | 4 | `motor_control.cpp`、`servo_control.cpp`、`imu_sensor.cpp`、`ir_receiver.cpp` |
| 反馈显示 | 1 | `led_display.cpp` |
| 优先级管理 | 1 | `priority_manager.cpp` |
| **合计** | **8** | |

---

## 🏷️ PlatformIO 项目结构

```
ESP32/
├── src/
│   ├── main.cpp
│   ├── motor_control.cpp
│   ├── servo_control.cpp
│   ├── ir_receiver.cpp
│   ├── imu_sensor.cpp
│   ├── led_display.cpp
│   └── priority_manager.cpp
├── include/
│   └── protocol.h
├── lib/
│   └── (第三方库：IRremote、MPU6050、Adafruit 库等)
├── platformio.ini
└── .gitignore
```

---

## 📦 `platformio.ini` 配置

```ini
[env:esp32-s3-devkitm-1]
platform = espressif32
board = esp32-s3-devkitm-1
framework = arduino
monitor_speed = 115200

lib_deps =
    arduino-libraries/IRremote
    electroniccats/MPU6050
    adafruit/Adafruit SSD1306
    adafruit/Adafruit NeoPixel
```

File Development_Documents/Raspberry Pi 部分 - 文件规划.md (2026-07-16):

# 🍓 Raspberry Pi 部分 - 文件规划

---

## 📊 总览：需要 14 个文件

| # | 文件名 | 核心功能 | 行数估算 |
|:-:|---|---|:---:|
| 1 | `main.py` | 程序入口，初始化所有模块，主循环 | ~80 |
| 2 | `config.py` | 所有配置参数（串口、摄像头、音频设备号） | ~40 |
| 3 | `requirements.txt` | Python 依赖列表 | ~10 |
| 4 | `motor_control.py` | 发送 `!MOTOR` 指令给 ESP32 | ~50 |
| 5 | `servo_control.py` | 发送 `!PAN` / `!TILT` / `!TRAY` 指令 | ~60 |
| 6 | `face_detector.py` | MediaPipe 人脸检测，返回人脸坐标 | ~70 |
| 7 | `face_follower.py` | PID 算法，计算速度指令 | ~60 |
| 8 | `voice_recognizer.py` | Vosk 语音识别，返回文字 | ~60 |
| 9 | `voice_speaker.py` | Edge-TTS 语音合成，播放音频 | ~60 |
| 10 | `llm_chat.py` | Ollama 对话，生成回复 | ~50 |
| 11 | `mode_manager.py` | 遥控/跟随/送货 三模切换逻辑 | ~70 |
| 12 | `delivery_scenario.py` | 送货场景：寻人→跟随→送达→TTS | ~70 |
| 13 | `tray_compensation.py` | 防洒补偿：读取 IMU → 调整托盘舵机 | ~50 |
| 14 | `test_full.py` | 端到端自动化测试脚本 | ~80 |
| **合计** | | | **~810 行** |

---

## 📁 每个文件的详细说明

### 1. `main.py` — 程序入口

**功能**：
- 程序启动入口
- 初始化所有模块（摄像头、串口、麦克风、音箱、LLM）
- 主循环：
  1. 检测人脸 → 如果是跟随模式，计算速度 → 发指令给 ESP32
  2. 检测语音指令 → 如果有，执行对应动作
  3. 读取串口反馈（IMU、电池电量、遥控器按键）
  4. 更新 OLED 表情和 NeoPixel 灯效
- 处理 Ctrl+C 安全退出（停止电机、释放摄像头）

**伪代码**：
```python
def main():
    init_all_modules()
    while True:
        # 1. 人脸检测
        cx, cy = face_detector.get_center()
        # 2. 模式判断
        if mode == "follow":
            left, right = face_follower.compute(cx, cy)
            motor_control.move(left, right)
        # 3. 语音指令
        text = voice_recognizer.listen()
        if text:
            process_voice_command(text)
        # 4. 读取串口反馈
        read_serial_feedback()
        # 5. 更新表情和灯效
        update_leds_and_oled()
```

---

### 2. `config.py` — 配置文件

**功能**：
- 串口配置：`SERIAL_PORT`、`BAUDRATE`
- 摄像头配置：`CAMERA_ID`、`FRAME_WIDTH`、`FRAME_HEIGHT`
- 音频配置：`MIC_DEVICE`、`SPEAKER_DEVICE`
- PID 参数：`KP`、`KI`、`KD`
- 速度限制：`MAX_SPEED`、`MIN_SPEED`
- 模式名称：`MODE_REMOTE`、`MODE_FOLLOW`、`MODE_DELIVERY`

**示例**：
```python
# config.py
SERIAL_PORT = "/dev/ttyUSB0"   # Windows: "COM3"
BAUDRATE = 115200

CAMERA_ID = 0
FRAME_WIDTH = 640
FRAME_HEIGHT = 480

MIC_DEVICE = "plughw:1,0"      # 用 arecord -l 查看
SPEAKER_DEVICE = "plughw:2,0"  # 用 aplay -l 查看

KP = 0.5
KI = 0.0
KD = 0.05

MAX_SPEED = 80
MIN_SPEED = 20
```

---

### 3. `requirements.txt` — Python 依赖

**功能**：列出所有需要的 Python 库，方便 `pip install -r requirements.txt` 一键安装

```
opencv-python
mediapipe
pyserial
vosk
edge-tts
pygame
pyaudio
ollama
```

---

### 4. `motor_control.py` — 电机控制

**功能**：
- 向 ESP32 发送 `!MOTOR#L{left}#R{right}#END` 指令
- 包含 `move(left, right)` 方法
- 包含 `stop()` 方法（调用 `move(0, 0)`）
- 速度值范围：-100 ~ 100
- 自动限制速度在 ±100 范围内

**示例**：
```python
class MotorController:
    def __init__(self, ser):
        self.ser = ser
    
    def move(self, left, right):
        left = max(-100, min(100, left))
        right = max(-100, min(100, right))
        cmd = f"!MOTOR#L{left}#R{right}#END\n"
        self.ser.write(cmd.encode())
    
    def stop(self):
        self.move(0, 0)
```

---

### 5. `servo_control.py` — 舵机云台控制

**功能**：
- 向 ESP32 发送 `!PAN#{angle}#END`（左右旋转）
- 向 ESP32 发送 `!TILT#{angle}#END`（上下俯仰）
- 向 ESP32 发送 `!TRAY#{angle}#END`（托盘倾斜补偿）
- 角度范围：PAN: -90~90，TILT: -45~45，TRAY: -15~15
- 包含 `center()` 方法（一键回中）

**示例**：
```python
class ServoController:
    def __init__(self, ser):
        self.ser = ser
    
    def pan(self, angle):
        angle = max(-90, min(90, angle))
        self.ser.write(f"!PAN#{angle}#END\n".encode())
    
    def tilt(self, angle):
        angle = max(-45, min(45, angle))
        self.ser.write(f"!TILT#{angle}#END\n".encode())
    
    def tray(self, angle):
        angle = max(-15, min(15, angle))
        self.ser.write(f"!TRAY#{angle}#END\n".encode())
    
    def center(self):
        self.pan(0)
        self.tilt(0)
```

---

### 6. `face_detector.py` — 人脸检测

**功能**：
- 初始化 MediaPipe FaceDetection
- 读取摄像头每一帧
- 检测人脸，返回人脸中心坐标 `(cx, cy)`
- 如果没有检测到人脸，返回 `(None, None)`
- 坐标范围：`cx: 0~1`（0=最左，1=最右），`cy: 0~1`（0=最上，1=最下）

**示例**：
```python
class FaceDetector:
    def __init__(self, camera_id=0):
        self.cap = cv2.VideoCapture(camera_id)
        self.detection = mp.solutions.face_detection.FaceDetection(
            min_detection_confidence=0.7
        )
    
    def get_center(self):
        ret, frame = self.cap.read()
        if not ret:
            return (None, None)
        rgb = cv2.cvtColor(frame, cv2.COLOR_BGR2RGB)
        results = self.detection.process(rgb)
        if results.detections:
            bbox = results.detections[0].location_data.relative_bounding_box
            cx = bbox.xmin + bbox.width / 2
            cy = bbox.ymin + bbox.height / 2
            return (cx, cy)
        return (None, None)
```

---

### 7. `face_follower.py` — 人脸跟随算法（PID）

**功能**：
- 接收人脸中心坐标 `(cx, cy)`
- 计算误差：`error = cx - 0.5`
- PID 控制，输出左右轮速度
- 目标：让人脸保持在画面中央
- 如果人脸在中央且够大 → 前进
- 如果人脸在左侧 → 左转
- 如果人脸在右侧 → 右转

**伪代码**：
```python
class FaceFollower:
    def __init__(self, kp=0.5, ki=0.0, kd=0.05):
        self.kp = kp
        self.ki = ki
        self.kd = kd
        self.last_error = 0
        self.integral = 0
    
    def compute(self, cx, cy, face_width):
        if cx is None:
            return (0, 0)
        
        error = cx - 0.5  # 目标：人脸在画面中央
        
        # PID 计算转向量
        self.integral += error
        derivative = error - self.last_error
        turn = self.kp * error + self.ki * self.integral + self.kd * derivative
        self.last_error = error
        
        # 如果人脸够大 → 前进
        if face_width > 0.15:
            base_speed = 50
        else:
            base_speed = 20  # 太远就慢慢走
        
        left = base_speed - turn * 80
        right = base_speed + turn * 80
        
        return (int(left), int(right))
```

---

### 8. `voice_recognizer.py` — 语音识别（STT）

**功能**：
- 初始化 Vosk 中文模型
- 从 USB 麦克风录音
- 实时语音识别，返回识别文字
- 支持连续识别和单次识别两种模式
- 包含唤醒词检测（如 "Hey HomeBuddy"）

**示例**：
```python
class VoiceRecognizer:
    def __init__(self, model_path="vosk-model-cn", device="plughw:1,0"):
        self.model = vosk.Model(model_path)
        self.recognizer = vosk.KaldiRecognizer(self.model, 16000)
        self.audio = pyaudio.PyAudio()
        self.stream = self.audio.open(
            format=pyaudio.paInt16,
            channels=1,
            rate=16000,
            input=True,
            input_device_index=self._get_device_index(device),
            frames_per_buffer=8000
        )
    
    def listen_once(self, timeout=5):
        # 监听 5 秒，返回识别的文字
        pass
    
    def listen_continuous(self, callback):
        # 持续监听，有识别结果就调用 callback
        pass
```

---

### 9. `voice_speaker.py` — 语音合成（TTS）

**功能**：
- 使用 Edge-TTS 生成语音（在线）
- 或使用 espeak 生成语音（离线）
- 通过 USB 音箱播放音频
- 包含 `speak(text)` 方法
- 支持打断（播放过程中停止）

**示例**：
```python
class VoiceSpeaker:
    def __init__(self, device="plughw:2,0"):
        self.device = device
        self.is_playing = False
    
    def speak(self, text):
        # 使用 edge-tts 生成音频
        import edge_tts
        import pygame
        # ... 生成并播放
        self.is_playing = True
        # ... 播放完成后设置为 False
    
    def stop(self):
        # 停止当前播放
        pygame.mixer.music.stop()
        self.is_playing = False
```

---

### 10. `llm_chat.py` — 大语言模型对话

**功能**：
- 连接本地 Ollama 服务
- 加载 Gemma 2B 或 Phi-3 模型
- 发送用户消息，返回 LLM 回复
- 维护对话历史（上下文）
- 超时处理（LLM 响应慢时不卡死）

**示例**：
```python
class ChatLLM:
    def __init__(self, model="gemma:2b", ollama_url="http://localhost:11434"):
        self.model = model
        self.url = ollama_url
        self.history = []
    
    def chat(self, user_message):
        self.history.append({"role": "user", "content": user_message})
        response = requests.post(
            f"{self.url}/api/chat",
            json={"model": self.model, "messages": self.history}
        )
        reply = response.json()["message"]["content"]
        self.history.append({"role": "assistant", "content": reply})
        return reply
    
    def clear_history(self):
        self.history = []
```

---

### 11. `mode_manager.py` — 模式管理

**功能**：
- 管理三种模式：遥控、跟随、送货
- 提供 `switch_mode(mode)` 方法
- 模式切换时执行对应的初始化和清理动作
- 当前模式状态查询
- 模式切换回调（如切换模式时播报 TTS）

**伪代码**：
```python
class ModeManager:
    MODES = ["remote", "follow", "delivery"]
    
    def __init__(self):
        self.current_mode = "remote"
    
    def switch_to(self, mode):
        if mode not in self.MODES:
            return False
        # 退出当前模式
        self._exit_mode(self.current_mode)
        # 进入新模式
        self.current_mode = mode
        self._enter_mode(mode)
        return True
    
    def _enter_mode(self, mode):
        if mode == "follow":
            # 启动人脸跟随
            pass
        elif mode == "delivery":
            # 启动送货场景
            pass
    
    def get_mode(self):
        return self.current_mode
```

---

### 12. `delivery_scenario.py` — 送货场景

**功能**：
- 触发条件：语音 "送水给我" 或 遥控器按 6
- 流程：
  1. 寻找目标人脸（原地旋转扫描）
  2. 锁定人脸 → 切换到跟随模式
  3. 跟随前进
  4. 到达目标（人脸足够大）→ 停止
  5. 播报 TTS："水送到了，主人请拿好"
  6. 回到待机模式
- 超时处理：如果 30 秒找不到人脸，播报 "没找到你"

**伪代码**：
```python
class DeliveryScenario:
    def __init__(self, face_detector, face_follower, motor, speaker):
        self.face_detector = face_detector
        self.face_follower = face_follower
        self.motor = motor
        self.speaker = speaker
    
    def run(self):
        self.speaker.speak("好的，马上送到")
        # 1. 寻找人脸（原地旋转）
        found = self._search_face(timeout=30)
        if not found:
            self.speaker.speak("没找到你")
            return
        # 2. 跟随
        self._follow_to_target()
        # 3. 到达
        self.motor.stop()
        self.speaker.speak("水送到了，主人请拿好")
    
    def _search_face(self, timeout):
        # 原地旋转扫描
        pass
    
    def _follow_to_target(self):
        # 跟随直到人脸足够大
        pass
```

---

### 13. `tray_compensation.py` — 防洒补偿

**功能**：
- 从 ESP32 读取 MPU6050 姿态数据（`!IMU#ROLL#PITCH#END`）
- 检测车身倾斜角度
- 计算托盘舵机补偿角度
- 发送 `!TRAY#{angle}#END` 指令
- 实时补偿，保持托盘水平

**伪代码**：
```python
class TrayCompensation:
    def __init__(self, servo_controller):
        self.servo = servo_controller
        self.roll = 0
        self.pitch = 0
    
    def update(self, roll, pitch):
        # 反向补偿
        comp_roll = -roll * 0.8
        comp_pitch = -pitch * 0.8
        # 限制角度
        comp_roll = max(-15, min(15, comp_roll))
        comp_pitch = max(-15, min(15, comp_pitch))
        self.servo.tray(comp_roll)
```

---

### 14. `test_full.py` — 端到端测试

**功能**：
- 一键运行所有功能测试
- 测试内容：
  1. 串口通信是否正常
  2. 电机是否能转动
  3. 舵机是否能转动
  4. 人脸检测是否正常
  5. 语音识别是否正常
  6. 语音合成是否正常
  7. 人脸跟随是否正常
  8. 送货场景是否正常
- 输出测试报告（通过/失败）

---

## 📊 文件依赖关系

```
main.py
  ├── config.py
  ├── motor_control.py
  ├── servo_control.py
  ├── face_detector.py
  │   └── face_follower.py
  ├── voice_recognizer.py
  ├── voice_speaker.py
  ├── llm_chat.py
  ├── mode_manager.py
  │   ├── delivery_scenario.py
  │   └── tray_compensation.py
  └── test_full.py (独立，用于测试)

所有文件 → 依赖 config.py
```

---

## ✅ 总结

| 类别 | 文件数量 | 说明 |
|---|:---:|---|
| 核心文件 | 3 | `main.py`、`config.py`、`requirements.txt` |
| 控制类 | 2 | `motor_control.py`、`servo_control.py` |
| AI 视觉类 | 2 | `face_detector.py`、`face_follower.py` |
| AI 语音类 | 2 | `voice_recognizer.py`、`voice_speaker.py` |
| AI 对话类 | 1 | `llm_chat.py` |
| 场景管理 | 3 | `mode_manager.py`、`delivery_scenario.py`、`tray_compensation.py` |
| 测试 | 1 | `test_full.py` |
| **合计** | **14** | |

---

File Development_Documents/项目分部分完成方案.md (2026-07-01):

# 🏠 HomeBuddy - 完整开发任务清单（5 大部分）

---

## Part 1 🔩 硬件平台搭建

> **目标**：让机器人有一个稳定的物理平台，所有硬件固定好，能通电，能用手推着走。
> **Git Tag**：`v0.1-hardware`

| # | 📋 任务 | 📝 说明 | 🚧 状态 |
|:-:|---|---|:---:|
| 1.1 | 🛞 底盘制作/采购 | 30×25cm 亚克力板或 3D 打印，标记好所有孔位 | ❌ |
| 1.2 | 🔩 电机 + 轮子安装 | 固定 L298N、2 个直流电机、橡胶轮、万向轮到底盘上 | ❌ |
| 1.3 | 🧱 分层堆叠 | 用铜柱分三层：底层（电池+L298N）、中层（ESP32）、上层（树莓派） | ❌ |
| 1.4 | 📷 摄像头 + 云台固定 | 将 USB Webcam 固定在 SG90 舵机云台上 | ❌ |
| 1.5 | 🔌 所有硬件固定 | 用扎带 + 纳米胶把树莓派、ESP32、传感器全部固定牢 | ❌ |
| 1.6 | 🔋 供电系统测试 | 验证：移动电源 → 树莓派 + ESP32；锂电池 → L298N | ❌ |
| 1.7 | 🧪 通电验证 | 插电后树莓派绿灯亮、ESP32 灯亮、L298N 灯亮 | ❌ |

### 📁 本部分产出文件

| 文件 | 说明 |
|---|---|
| `README.md` | 项目介绍 |
| `docs/project-plan.md` | 完整项目方案 |
| `docs/wiring-guide.md` | 接线指南 |
| `docs/hardware-checklist.md` | 硬件清单 |

### 🏷️ 本部分 Git 提交

```bash
git add docs/ README.md
git commit -m "Part 1: 硬件平台搭建完成"
git tag v0.1-hardware
```

---

## Part 2 ⚙️ 执行器固件开发

> **目标**：ESP32 能够接收串口指令并控制所有硬件（电机、舵机、OLED、NeoPixel、MPU6050）。
> **Git Tag**：`v0.2-executor`

| # | 📋 任务 | 📝 说明 | 🚧 状态 |
|:-:|---|---|:---:|
| 2.1 | 📡 串口通信基础 | 树莓派 ↔ ESP32 UART 连接，能互相收发数据 | ❌ |
| 2.2 | 🚗 电机控制 | 解析 `!MOTOR#L{左}#R{右}#END` → L298N 输出 PWM | ❌ |
| 2.3 | 🦾 舵机云台控制 | 解析 `!PAN` / `!TILT` → 控制 SG90 转到指定角度 | ❌ |
| 2.4 | 🖥️ OLED 表情 | 解析 `!EMOJI` → 显示 😊 🎯 😢 🤖 | ❌ |
| 2.5 | 💡 NeoPixel 灯效 | 解析 `!RGB` → 显示红/绿/蓝/黄等状态颜色 | ❌ |
| 2.6 | 🧭 MPU6050 读取 | 每 100ms 发送 `!IMU#ROLL#PITCH#END` 给树莓派 | ❌ |
| 2.7 | 🔋 ADC 电量监测 | 读取锂电池电压，发送 `!BATTERY#{电压}#END` | ❌ |
| 2.8 | 📋 协议文档 | 在 `docs/protocol.md` 记录所有指令格式 | ❌ |

### 📁 本部分产出文件

| 文件 | 说明 |
|---|---|
| `esp32/src/main.cpp` | ESP32 主程序 |
| `esp32/src/motor_control.cpp` | L298N 驱动 |
| `esp32/src/servo_control.cpp` | SG90 控制 |
| `esp32/src/imu_sensor.cpp` | MPU6050 |
| `esp32/src/oled_display.cpp` | SSD1306 |
| `esp32/src/neopixel_led.cpp` | NeoPixel |
| `esp32/include/protocol.h` | 协议定义 |
| `esp32/platformio.ini` | PlatformIO 配置 |
| `docs/protocol.md` | 通信协议文档 |

### 🏷️ 本部分 Git 提交

```bash
git add esp32/ docs/protocol.md
git commit -m "Part 2: 执行器固件开发完成"
git tag v0.2-executor
```

---

## Part 3 🎮 遥控控制

> **目标**：红外遥控器能控制机器人移动和云台，作为最可靠的手动控制方式。
> **Git Tag**：`v0.3-remote`

| # | 📋 任务 | 📝 说明 | 🚧 状态 |
|:-:|---|---|:---:|
| 3.1 | 📟 HX1838 解码 | 烧录 IRrecv 示例程序，读取并记录每个按键的编码 | ❌ |
| 3.2 | 🗺️ 按键映射表 | 建立按键编码 → 功能（前进/后退/左转/右转/停止/云台） | ❌ |
| 3.3 | 🚗 方向键控制 | ↑↓←→ 控制移动，OK 键紧急停止（最高优先级） | ❌ |
| 3.4 | 🔄 数字键控制云台 | 1 回中，2/3 左右转，4/5 上下俯仰 | ❌ |
| 3.5 | ⏩ 速度调节 | * 键加速，# 键减速，设置 3 档可调速度 | ❌ |
| 3.6 | 📟 遥控优先级机制 | 按下方向键 → 立即暂停所有自动模式，手动接管 | ❌ |
| 3.7 | 🔄 模式切换键 | 按 0 键循环切换：遥控模式 ↔ 跟随模式 ↔ 送货模式 | ❌ |

### 📁 本部分产出文件

| 文件 | 说明 |
|---|---|
| `esp32/src/ir_receiver.cpp` | HX1838 完整解码 |
| `esp32/include/remote_mapping.h` | 按键映射表 |
| `esp32/src/priority_manager.cpp` | 控制优先级管理 |
| `docs/remote-control-guide.md` | 遥控器使用说明 |

### 🏷️ 本部分 Git 提交

```bash
git add esp32/src/ir_receiver.cpp esp32/include/remote_mapping.h docs/remote-control-guide.md
git commit -m "Part 3: 遥控控制完成"
git tag v0.3-remote
```

---

## Part 4 🧠 树莓派 AI 核心

> **目标**：树莓派实现人脸检测、语音识别、语音合成、智能对话四大 AI 能力。
> **Git Tag**：`v0.4-ai`

| # | 📋 任务 | 📝 说明 | 🚧 状态 |
|:-:|---|---|:---:|
| 4.1 | 📷 USB Webcam 测试 | 用 `cv2.VideoCapture(0)` 确认画面正常显示 | ❌ |
| 4.2 | 👁️ MediaPipe 人脸检测 | 画面中框出人脸，输出人脸中心坐标 (cx, cy) | ❌ |
| 4.3 | 🎤 USB 麦克风测试 | 用 `arecord` 录音测试，确认设备号 | ❌ |
| 4.4 | 🎤 Vosk STT 集成 | 录音 → 离线识别 → 输出中文文字 | ❌ |
| 4.5 | 🔊 USB 音箱测试 | 用 `aplay` 播放测试，确认设备号 | ❌ |
| 4.6 | 🔊 Edge-TTS 集成 | 文字 → 生成音频 → 音箱播报 | ❌ |
| 4.7 | 🤖 Ollama 集成 | 安装 Ollama，下载 Gemma 2B 模型，测试对话 | ❌ |
| 4.8 | 🎯 人脸跟随算法 | 人脸偏移 → PID 计算 → 生成速度指令 (`!MOTOR`) | ❌ |

### 📁 本部分产出文件

| 文件 | 说明 |
|---|---|
| `raspberry_pi/main.py` | AI 主程序入口 |
| `raspberry_pi/face_detection.py` | MediaPipe 人脸检测 |
| `raspberry_pi/face_follower.py` | 人脸跟随算法 (PID) |
| `raspberry_pi/voice_stt.py` | Vosk 语音识别 |
| `raspberry_pi/voice_tts.py` | Edge-TTS 语音合成 |
| `raspberry_pi/llm_chat.py` | Ollama 对话 |
| `raspberry_pi/config.py` | 配置文件（设备号、参数） |
| `raspberry_pi/requirements.txt` | Python 依赖列表 |
| `docs/audio-setup.md` | 音频设备配置指南 |
| `.gitignore` | 忽略 `__pycache__` / 大模型文件 |

### 🏷️ 本部分 Git 提交

```bash
git add raspberry_pi/ docs/audio-setup.md .gitignore
git commit -m "Part 4: 树莓派 AI 核心完成"
git tag v0.4-ai
```

---

## Part 5 🎯 系统整合与场景

> **目标**：所有模块整合，实现完整的用户场景：语音对话、遥控控制、人脸跟随、自动送货。
> **Git Tag**：`v1.0-beta`

| # | 📋 任务 | 📝 说明 | 🚧 状态 |
|:-:|---|---|:---:|
| 5.1 | 🔗 树莓派 ↔ ESP32 联动 | 树莓派人脸跟随 → 串口发 `!MOTOR` → ESP32 执行 | ❌ |
| 5.2 | 🎯 人脸跟随完整测试 | 人在前面走，机器人自动跟随，OLED 显示 🎯 | ❌ |
| 5.3 | 🗣️ 语音 → 动作联动 | "左转" → STT → 树莓派 → ESP32 → 电机左转 | ❌ |
| 5.4 | 📟 遥控 → 树莓派联动 | 遥控按 8 → ESP32 → 树莓派 → 启动人脸跟随 | ❌ |
| 5.5 | 📦 送货场景端到端 | "送水给我" → 寻人 → 跟随 → 到达 → 停止 → TTS："水送到了" | ❌ |
| 5.6 | 🧊 防洒补偿测试 | 急刹时 MPU6050 检测倾斜 → 托盘舵机反向补偿 | ❌ |
| 5.7 | 🔄 三模切换测试 | 遥控模式 ↔ 跟随模式 ↔ 送货模式，切换流畅无卡顿 | ❌ |
| 5.8 | 🧪 端到端测试脚本 | 编写 `test_full.py`，一键运行全部功能测试 | ❌ |
| 5.9 | 📖 用户手册 | 写完 `docs/user-manual.md`，包含所有功能说明 | ❌ |

### 📁 本部分产出文件

| 文件 | 说明 |
|---|---|
| `raspberry_pi/main.py` | 完整版主程序（三模整合） |
| `raspberry_pi/mode_manager.py` | 模式管理（遥控/跟随/送货） |
| `raspberry_pi/delivery_scenario.py` | 送货场景逻辑 |
| `raspberry_pi/tray_compensation.py` | 防洒补偿算法 |
| `raspberry_pi/test_full.py` | 端到端自动化测试脚本 |
| `docs/user-manual.md` | 用户手册 |

### 🏷️ 本部分 Git 提交

```bash
git add raspberry_pi/ docs/user-manual.md README.md
git commit -m "Part 5: 系统整合与场景完成"
git tag v1.0-beta
```

---

## 🏁 最终发布 v1.0

> **目标**：全面回归测试，清理代码，正式发布稳定版本。
> **Git Tag**：`v1.0`

| # | 📋 任务 | 📝 说明 | 🚧 状态 |
|:-:|---|---|:---:|
| F.1 | 🧪 全面回归测试 | 所有 Part 1-5 的功能重新跑一遍 | ❌ |
| F.2 | 📝 更新 README | 添加完整使用说明 + 硬件照片/截图 | ❌ |
| F.3 | 📖 更新用户手册 | 确认所有功能描述准确无误 | ❌ |
| F.4 | 🐛 修复所有已知 Bug | 确保没有遗留的已知问题 | ❌ |
| F.5 | 📦 整理代码 | 删除调试代码，添加完整注释 | ❌ |

### 🏷️ 最终 Git 提交

```bash
git checkout main
git merge dev
git tag v1.0
git push origin main --tags
```

---

## 📊 总览进度看板

| Part | 名称 | 任务数 | Tag | 完成度 |
|:----:|---|:-----:|-----|:---:|
| 1 | 🔩 硬件平台搭建 | 7 | `v0.1-hardware` | 0 / 7 |
| 2 | ⚙️ 执行器固件开发 | 8 | `v0.2-executor` | 0 / 8 |
| 3 | 🎮 遥控控制 | 7 | `v0.3-remote` | 0 / 7 |
| 4 | 🧠 树莓派 AI 核心 | 8 | `v0.4-ai` | 0 / 8 |
| 5 | 🎯 系统整合与场景 | 9 | `v1.0-beta` | 0 / 9 |
| 发布 | 🏁 正式发布 v1.0 | 5 | `v1.0` | 0 / 5 |
| **合计** | | **44** | | **0 / 44** |

---

> 🚀 **建议**：把这份清单复制到你的项目根目录 `docs/TODO.md`，每完成一个任务就把 `❌` 改成 `✅`，进度一目了然！

---

**🏠 HomeBuddy · 开始设计吧！** ❤️

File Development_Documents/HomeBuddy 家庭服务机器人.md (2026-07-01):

# 🏠 HomeBuddy 家庭服务机器人 · 终极版项目方案

> **版本**：v1.2
> **更新日期**：2026-07-01
> **更新说明**：更新采购方式为购买或 3D 打印；精简供电结构；移除手机 App 控制；调整实施计划为任务模块形式。

---

## 📖 目录

1. [项目概述](#1-项目概述)
2. [系统架构](#2-系统架构)
3. [硬件清单](#3-硬件清单)
4. [接线方案](#4-接线方案)
5. [通信协议](#5-通信协议)
6. [控制方式](#6-控制方式)
7. [功能模块](#7-功能模块)
8. [实施任务](#8-实施任务)
9. [验收标准](#9-验收标准)
10. [风险与应对](#10-风险与应对)
11. [后期扩展](#11-后期扩展)

## 1. 项目概述

| 项目 | 内容 |
|---|---|
| 🏠 项目名称 | **HomeBuddy**（家庭伙伴） |
| 🎯 定位 | 家庭智能服务机器人 |
| ✨ 核心功能 | 🗣️ 语音对话 · 👁️ 人脸跟随 · 🎮 遥控控制 · 📦 自动送货 |
| 🧠 架构 | 树莓派（主脑）+ ESP32-S3（执行器） |
| 🎛️ 控制方式 | 语音 🎤 + 遥控器 📟（双模） |

### 🧭 设计原则

| 原则 | 说明 |
|---|---|
| 🔹 职责分离 | 树莓派管 AI，ESP32 管硬件 |
| 🔹 有线通信 | UART 串口，稳定可靠 |
| 🔹 双重控制 | 语音 + 遥控，随时切换 |
| 🔹 安全优先 | 遥控器随时接管，紧急制动 |
| 🔹 即插即用 | 音频设备全 USB，无需额外驱动 |

## 2. 系统架构

```
┌─────────────────────────────────────────────────────────────────┐
│                      👤 用户交互层                              │
│  ┌─────────────────────┐  ┌─────────────────────┐            │
│  │      🎤 语音控制    │  │     📟 遥控器控制   │            │
│  │  （自然语言指令）   │  │  （红外物理按键）   │            │
│  └──────────┬──────────┘  └──────────┬──────────┘            │
│             └────────────┬────────────┘                       │
└──────────────────────────┼────────────────────────────────────┘
                           │
┌──────────────────────────┼────────────────────────────────────┐
│                          ▼                                     │
│              🧠 树莓派 4B（主脑 / 8GB）                       │
│  ┌────────────────────────────────────────────────────────┐   │
│  │  📦 软件功能：                                        │   │
│  │  🎤 Vosk STT（语音识别）                             │   │
│  │  🔊 Edge-TTS（语音合成）                             │   │
│  │  🤖 Ollama（本地 LLM / Gemma 2B）                   │   │
│  │  👁️ MediaPipe（人脸检测）                            │   │
│  │  🎯 人脸跟随算法（PID 控制）                         │   │
│  │  🔄 模式管理（遥控 / 跟随 / 送货）                   │   │
│  └──────────────────┬─────────────────────────────────────┘   │
│                     │ 🔗 UART 串口（GPIO14/15）                │
│                     │ 📨 指令协议                             │
│                     │ 🔋 供电：移动电源（USB-C）              │
└─────────────────────┼────────────────────────────────────────┘
                      │
┌─────────────────────┼────────────────────────────────────────┐
│                     ▼                                         │
│            ⚙️ ESP32-S3（执行器 / 小脑）                       │
│  ┌────────────────────────────────────────────────────────┐   │
│  │  🔧 硬件控制：                                        │   │
│  │  🚗 L298N → 直流电机 ×2（轮子）                      │   │
│  │  🦾 SG90 舵机 ×3-4（云台 / 托盘 / 头部）            │   │
│  │  🧭 MPU6050（姿态检测 / 防洒补偿）                   │   │
│  │  📟 HX1838（红外遥控接收）                           │   │
│  │  🖥️ OLED SSD1306（表情显示）                         │   │
│  │  💡 NeoPixel（RGB 状态灯光）                         │   │
│  │  🔋 ADC（电量监测）                                  │   │
│  └────────────────────────────────────────────────────────┘   │
└─────────────────────────────────────────────────────────────────┘
```

### 🎵 音频方案

```
┌─────────────────────────────────────────────────────┐
│              树莓派 USB 音频方案                    │
│  ┌───────────────┐    ┌───────────────┐           │
│  │  🎤 STJF USB  │    │  🔊 双喇叭    │           │
│  │  麦克风       │    │  USB 音箱     │           │
│  │  (语音输入)   │    │  (语音输出)   │           │
│  └───────┬───────┘    └───────┬───────┘           │
│          │                    │                    │
│          └────────┬───────────┘                    │
│                   ▼                                │
│          ┌─────────────────┐                       │
│          │  树莓派 USB口   │                       │
│          │  (即插即用)     │                       │
│          └─────────────────┘                       │
└─────────────────────────────────────────────────────┘
```

## 3. 硬件清单

### ✅ 已有硬件

| 组件 | 型号 | 数量 | 状态 |
|---|---|:----:|:----:|
| 🧠 主控1 | 树莓派 4B 8GB + 128GB | 1 | ✅ 已有 |
| ⚙️ 主控2 | ESP32-S3 DevKit | 1 | ✅ 已有 |
| 📷 摄像头 | USB Webcam 1080P | 1 | ✅ 已有 |
| 🎤 麦克风 | STJF mini USB 麦克风 | 1 | ✅ 已有 |
| 🔊 音箱 | 双喇叭 USB 音箱 | 1 | ✅ 已有 |
| 🔋 移动电源 | Power Bank（USB-C 输出） | 1 | ✅ 已有 |
| 🦾 舵机 | SG90 9g | 3-4 | ✅ 已有 |
| 🧭 陀螺仪 | MPU6050 | 1 | ✅ 已有 |
| 🚗 电机驱动 | L298N | 1 | ✅ 已有 |
| 🖥️ 显示屏 | OLED SSD1306 128x64 | 1 | ✅ 已有 |
| 💡 RGB灯 | NeoPixel | 1 | ✅ 已有 |
| 📟 红外接收 | HX1838 + 遥控器 | 1 | ✅ 已有 |
| 🎤 麦克风 | INMP441 | 1 | ⚠️ 备用 |
| 🔊 功放 | MAX98357A | 1 | ⚠️ 备用 |

### 🆕 需采购（购买或 3D 打印）

| 序号 | 物品 | 规格 | 数量 | 预算 | 备注 |
|:----:|---|---|:----:|---|---|
| 1 | 🛞 底盘 | 30×25cm 亚克力 / 3D 打印 | 1 | ¥20-40 | 购买成品或自行打印 |
| 2 | 🏎️ 橡胶轮 | 直径 8-10cm | 2 | ¥60-100 | 购买 |
| 3 | 🔄 万向轮 | 金属支架 | 1 | ¥15-20 | 购买 |
| 4 | 🔋 锂电池组 | 12V 3S 18650（带保护板） | 1 | ¥120-180 | 仅给 L298N + 电机供电 |
| 5 | 🔩 铜柱螺丝套件 | M2.5 / M3 各种长度 | 1套 | ¥20-30 | 购买 |
| 6 | 📡 杜邦线套装 | 公/母/母母头 | 1套 | ¥15 | 购买 |
| 7 | 🔌 USB 延长线 | 公对母 1米 | 1 | ¥10 | 灵活布置摄像头 |
| 8 | 🎗️ 扎带 + 纳米胶 | 杂 | 1包 | ¥10 | 购买 |
| 9 | 🖨️ 3D 打印耗材 | PLA / PETG（如需自行打印） | 1卷 | ¥60-100 | 可选 |

**总预算：约 ¥330-555**

## 4. 接线方案

### 4.1 🌲 树莓派端

| 接口 | → 连接对象 | 说明 |
|---|---|---|
| USB-A | 📷 USB Webcam | 视频输入 |
| USB-A | 🎤 STJF USB 麦克风 | 音频输入（语音识别） |
| USB-A | 🔊 双喇叭 USB 音箱 | 音频输出（TTS 播报） |
| USB-C | 🔋 移动电源 | 树莓派供电 |
| GPIO14 (TX) | ⚙️ ESP32 RX | 串口发送 |
| GPIO15 (RX) | ⚙️ ESP32 TX | 串口接收 |
| GND | ⚙️ ESP32 GND | 共地 |

### 4.2 ⚙️ ESP32 端

| 引脚 | → 连接对象 | 说明 |
|---|---|---|
| UART RX | 🌲 树莓派 TX | 接收指令 |
| UART TX | 🌲 树莓派 RX | 发送反馈 |
| GND | 🌲 树莓派 GND | 共地 |
| GPIO4 | 🚗 L298N IN1 | 左电机 A |
| GPIO5 | 🚗 L298N IN2 | 左电机 B |
| GPIO6 | 🚗 L298N IN3 | 右电机 A |
| GPIO7 | 🚗 L298N IN4 | 右电机 B |
| GPIO8 (PWM) | 🦾 SG90 舵机1 | 云台左右 |
| GPIO9 (PWM) | 🦾 SG90 舵机2 | 云台上下 |
| GPIO10 (PWM) | 🦾 SG90 舵机3 | 托盘补偿 |
| GPIO13 | 📟 HX1838 OUT | 红外接收 |
| GPIO21 (SDA) | 🧭 MPU6050 SDA | I2C 数据 |
| GPIO22 (SCL) | 🧭 MPU6050 SCL | I2C 时钟 |
| GPIO21 (SDA) | 🖥️ OLED SDA | 与 MPU6050 并联 |
| GPIO22 (SCL) | 🖥️ OLED SCL | 与 MPU6050 并联 |
| GPIO48 | 💡 NeoPixel DATA | RGB 指示灯 |
| GPIO32 (ADC) | 🔋 电池电压采样 | 分压电阻 |
| VIN (5V) | 🔋 移动电源（USB-A 或 USB-C） | ESP32 供电 |

### 4.3 🔋 供电系统

```
🔋 移动电源（Power Bank）
    ├── USB-C → 🌲 树莓派（5V 供电）
    └── USB-A → ⚙️ ESP32-S3（5V 供电）

🔋 12V 锂电池组（3S 18650，独立供电）
    └── 🚗 直接 → L298N（电机驱动，12V 输入）
```

**供电分工**：

| 电源 | 供电对象 | 说明 |
|---|---|---|
| 🔋 移动电源 | 🌲 树莓派 + USB外设 + ⚙️ ESP32 | 5V 输出，稳定供电 |
| 🔋 12V 锂电池组 | 🚗 L298N + 电机 | 独立供电，大电流不干扰控制电路 |

> ✅ **优点**：树莓派 + ESP32 和电机电源完全隔离，互不干扰，避免电机启动瞬间拉低电压导致主控重启

## 5. 通信协议

### 5.1 🌲 树莓派 → ⚙️ ESP32（指令）

| 指令格式 | 参数 | 功能 |
|---|---|---|
| `!MOTOR#L{左}#R{右}#END` | -100 ~ 100 | 🚗 两轮差速控制 |
| `!PAN#{角度}#END` | -90 ~ 90 | 🔄 云台水平旋转 |
| `!TILT#{角度}#END` | -45 ~ 45 | 🔄 云台俯仰 |
| `!TRAY#{角度}#END` | -15 ~ 15 | 📦 托盘倾斜补偿 |
| `!EMOJI#{ID}#END` | 0=😊 1=🎯 2=😢 3=🤖 | 🖥️ 表情切换 |
| `!RGB#R{红}#G{绿}#B{蓝}#END` | 0~255 | 💡 RGB 灯色 |
| `!MODE#{模式}#END` | 0=遥控 1=跟随 2=送货 | 🔄 模式切换 |
| `!STOP#END` | — | 🛑 紧急停止 |

### 5.2 ⚙️ ESP32 → 🌲 树莓派（反馈）

| 反馈格式 | 频率 | 功能 |
|---|:----:|---|
| `!IMU#ROLL{角度}#PITCH{角度}#END` | 10Hz | 🧭 姿态数据 |
| `!BATTERY#{电压}#END` | 1Hz | 🔋 电机电池电压 |
| `!IR#{按键码}#END` | 事件触发 | 📟 遥控器按键 |

## 6. 控制方式

### 🎛️ 双模控制

| 模式 | 触发方式 | 说明 |
|---|---|---|
| 🎮 **遥控模式** | 红外遥控器 | 手动控制移动和云台 |
| 👁️ **跟随模式** | 语音 / 遥控器切换 | 自动人脸跟随 |
| 📦 **送货模式** | 语音 "送水给我" | 自动寻人 + 送达 |

### 📟 红外遥控器按键映射（17 键标准版）

| 按键 | 功能 | 优先级 |
|---|---|:----:|
| **方向区** | | |
| ↑ | 🚗 前进 | ⭐⭐⭐ |
| ↓ | 🚗 后退 | ⭐⭐⭐ |
| ← | 🔄 左转 | ⭐⭐⭐ |
| → | 🔄 右转 | ⭐⭐⭐ |
| **控制区** | | |
| OK | 🛑 紧急停止 | ⭐⭐⭐ |
| 0 | 🔄 模式切换（遥控 ↔ 跟随 ↔ 送货） | ⭐⭐ |
| 1 | 🎯 云台回中 | ⭐⭐ |
| 2 | 🔄 云台左转 15° | ⭐⭐ |
| 3 | 🔄 云台右转 15° | ⭐⭐ |
| 4 | 🔄 云台上仰 15° | ⭐⭐ |
| 5 | 🔄 云台下俯 15° | ⭐⭐ |
| **快捷区** | | |
| 6 | 📦 送货指令 | ⭐⭐ |
| 7 | 👋 打招呼（TTS："你好呀！"） | ⭐ |
| 8 | 👁️ 启动人脸跟随 | ⭐⭐ |
| 9 | 🏠 返回充电位（预留） | ⭐ |
| \* | ⏩ 加速 | ⭐ |
| \# | ⏪ 减速 | ⭐ |

### ⚡ 控制优先级

```
🥇 最高：遥控器方向键 + OK（任何时候都生效）
🥈 中等：遥控器功能键
🥉 正常：语音控制 + 自动跟随
```

> 🔒 **安全机制**：按下方向键 → 自动暂停所有自动模式 → 手动接管

## 7. 功能模块

| 模块 | 负责芯片 | 功能 | 优先级 |
|---|---|---|:----:|
| 🎤 语音识别 | 树莓派 | STJF USB麦克风 → Vosk STT | 🔴 P0 |
| 🔊 语音合成 | 树莓派 | Edge-TTS → 双喇叭 USB音箱 | 🔴 P0 |
| 🤖 智能对话 | 树莓派 | Ollama（Gemma 2B） | 🔴 P0 |
| 👁️ 人脸检测 | 树莓派 | MediaPipe + USB Webcam | 🔴 P0 |
| 🎯 人脸跟随 | 树莓派 | PID控制 + 速度映射 | 🔴 P0 |
| 📟 红外遥控 | ESP32 | HX1838 信号解码 | 🔴 P0 |
| 🚗 电机控制 | ESP32 | L298N PWM 调速 | 🔴 P0 |
| 🦾 舵机云台 | ESP32 | SG90 角度控制 | 🔴 P0 |
| 🔄 模式管理 | 树莓派 | 三模切换逻辑 | 🟡 P1 |
| 🧭 姿态检测 | ESP32 | MPU6050 读取 | 🟡 P1 |
| 📦 防洒补偿 | ESP32 | 姿态 → 舵机反向补偿 | 🟡 P1 |
| 🖥️ 表情显示 | ESP32 | OLED 动态表情 | 🟡 P1 |
| 💡 状态灯效 | ESP32 | NeoPixel RGB | 🟡 P1 |
| 🔋 电量监测 | ESP32 | ADC 电压采样 | 🟢 P2 |

**优先级说明**：
- 🔴 P0 = 核心功能，必须实现
- 🟡 P1 = 重要功能，提升体验
- 🟢 P2 = 锦上添花，后期迭代

## 8. 实施任务

### 🔧 硬件搭建任务

| 序号 | 任务 | 说明 |
|:----:|---|---|
| 1 | 🛞 底盘制作 | 购买亚克力板或 3D 打印底盘，尺寸 30×25cm |
| 2 | 🔩 电机安装 | 固定 L298N + 直流电机 + 轮子到底盘 |
| 3 | 🧱 分层堆叠 | 铜柱分层固定：底层电池+L298N，中层 ESP32，上层树莓派 |
| 4 | 📷 摄像头固定 | USB Webcam 安装在舵机云台上 |
| 5 | 🔌 线路连接 | 按接线方案连接所有硬件（树莓派 + ESP32 + 传感器 + 电机） |
| 6 | 🔋 供电测试 | 验证移动电源给树莓派/ESP32，锂电池给 L298N |
| 7 | 📟 红外解码 | 烧录 IRrecv 示例，读取遥控器每个按键的编码值 |

### 💻 软件开发任务（按顺序执行）

| 序号 | 模块 | 说明 |
|:----:|---|---|
| 1 | ⚙️ ESP32 串口通信 | 实现 `!MOTOR` / `!PAN` / `!TILT` 等指令解析 |
| 2 | ⚙️ ESP32 电机测试 | 手动发指令验证 L298N 正反转 |
| 3 | ⚙️ ESP32 舵机测试 | 手动发指令验证 SG90 角度控制 |
| 4 | ⚙️ ESP32 红外解码 | 将遥控器按键映射为具体动作 |
| 5 | ⚙️ ESP32 MPU6050 | 读取姿态数据并通过串口发送给树莓派 |
| 6 | ⚙️ ESP32 OLED + NeoPixel | 表情切换 + 状态灯效 |
| 7 | 🌲 树莓派 USB 音频 | 测试录音（麦克风）和播放（音箱） |
| 8 | 🌲 树莓派 Vosk STT | 离线语音识别，输出识别文字 |
| 9 | 🌲 树莓派 Edge-TTS | 文字转语音，音箱播报 |
| 10 | 🌲 树莓派 MediaPipe | USB Webcam 人脸检测（画面框出人脸） |
| 11 | 🌲 树莓派 人脸跟随 | 计算人脸偏移 → PID → 发 `!MOTOR` 指令给 ESP32 |
| 12 | 🌲 树莓派 Ollama | 集成本地 LLM 对话能力 |
| 13 | 🔄 模式管理 | 实现遥控 / 跟随 / 送货三模切换 |
| 14 | 🧪 全系统联调 | 语音触发 → 人脸跟随 → 送货到达 → TTS 播报 |

### 🧪 测试与调试任务

| 序号 | 任务 | 说明 |
|:----:|---|---|
| 1 | 🚗 遥控移动测试 | 遥控器控制前进/后退/转向，检查响应速度 |
| 2 | 🎯 人脸跟随测试 | 人在前方移动，机器人自动跟随 |
| 3 | 🗣️ 语音交互测试 | 说"你好" → 识别 → LLM 回复 → TTS 播报 |
| 4 | 📦 送货场景测试 | 说"送水给我" → 寻人 → 送达 → 语音提示 |
| 5 | 🧊 防洒测试 | 急刹时观察托盘是否保持水平 |
| 6 | 🔋 续航测试 | 连续运行，记录电池使用时间 |
| 7 | 📟 红外遥控干扰测试 | 强光下、不同角度遥控是否灵敏 |
| 8 | 🎤 语音抗噪测试 | 电机运行时语音识别是否正常 |

## 9. 验收标准

### ✅ 功能验收

| 功能 | 验收条件 | 状态 |
|---|---|:----:|
| 🎮 遥控移动 | 方向键控制前进/后退/转向流畅 | ⬜ 待测 |
| 🔄 云台控制 | 摄像头平滑旋转 | ⬜ 待测 |
| 👁️ 人脸检测 | 屏幕框出人脸并显示坐标 | ⬜ 待测 |
| 🎯 人脸跟随 | 机器人跟随人在房间移动 | ⬜ 待测 |
| 🎤 语音识别 | STJF 麦克风准确识别中文指令 | ⬜ 待测 |
| 🔊 语音合成 | 双喇叭音箱播报 TTS 语音清晰 | ⬜ 待测 |
| 📦 自动送货 | "送水" → 寻人 → 送达 | ⬜ 待测 |
| 📟 红外遥控 | 所有按键功能正常 | ⬜ 待测 |
| 🧊 防洒功能 | 急刹时托盘倾斜补偿有效 | ⬜ 待测 |
| 🖥️ 表情显示 | OLED 切换不同表情 | ⬜ 待测 |
| 💡 状态灯效 | RGB 灯显示不同颜色状态 | ⬜ 待测 |
| 🔄 模式切换 | 遥控/跟随/送货 三模切换流畅 | ⬜ 待测 |
| 🔋 双电源供电 | 移动电源 + 锂电池组同时工作稳定 | ⬜ 待测 |

### 📊 性能验收

| 指标 | 要求 | 备注 |
|---|---|---|
| 🔋 续航时间 | ≥ 2 小时（连续移动） | 锂电池组容量决定 |
| 🔋 树莓派供电 | 移动电源独立供电 | 不受电机干扰 |
| 📦 最大载重 | ≥ 500g | 1瓶水 + 零食 |
| 🏎️ 最大速度 | 0.5 m/s | 家庭安全速度 |
| ⏱️ 跟随延迟 | < 200ms | 感觉不到卡顿 |
| 🎤 语音识别率 | > 80% | 安静环境 |
| 📟 遥控距离 | ≥ 8 米 | 室内足够 |
| 🔊 音箱音量 | 5米内清晰可闻 | 双喇叭有优势 |

## 10. 风险与应对

| ⚠️ 风险 | 📌 影响 | 🛠️ 应对措施 |
|---|---|---|
| 🔋 移动电源输出不足 | 树莓派降频/重启 | 使用支持 5V/3A 输出的移动电源 |
| 🔋 电机启动拉低电压 | ESP32 重启 | 树莓派/ESP32 与电机电源完全隔离 |
| 🎤 USB 麦克风延迟 | 语音交互卡顿 | 降低采样率 / 使用 ALSA 低延迟配置 |
| 🔊 USB 音箱无声 | TTS 播报失败 | 检查 ALSA 默认输出设备配置 |
| 📡 USB 口不够用 | 外设无法全部插入 | 树莓派4B有4个USB口，刚好够用；或加 USB HUB |
| 💧 托盘饮料倾倒 | 核心功能失败 | 梯形加减速 + MPU6050 硬件补偿 |
| 🌀 人脸跟随抖动 | 体验差 | PID 参数调优，降低响应灵敏度 |
| ☀️ 红外受强光干扰 | 遥控失效 | 避免阳光直射接收头 |

## 11. 后期扩展

| 功能 | 所需硬件 | 优先级 |
|---|---|:----:|
| 🚧 自动避障 | 超声波传感器 HC-SR04 | ⭐⭐⭐ |
| 🗺️ 地图构建 | 激光雷达 RPLIDAR | ⭐⭐ |
| 🔋 自动回充 | 充电座 + 红外引导 | ⭐⭐ |
| 📹 远程监控 | 摄像头推流（已有） | ⭐⭐⭐ |
| ✋ 手势识别 | 现有摄像头 | ⭐⭐ |
| 📦 物体识别 | 现有摄像头 + YOLO | ⭐⭐ |
| 🌍 多语言支持 | 更换 Vosk 模型 | ⭐ |

## 📌 附录

### A. 音频设备配置要点

| 设备 | 配置方法 |
|---|---|
| 🎤 STJF USB 麦克风 | `arecord -l` 查看设备号，Vosk 中指定 `device` |
| 🔊 双喇叭 USB 音箱 | `aplay -l` 查看设备号，Pygame 中指定输出设备 |
| 🎵 音量控制 | `alsamixer` 调整 USB 音箱音量 |

**树莓派 USB 音频测试命令**：
```bash
# 测试录音（STJF 麦克风）
arecord -D plughw:1,0 -d 5 -f S16_LE -r 16000 test.wav

# 测试播放（双喇叭音箱）
aplay -D plughw:2,0 test.wav
```

### B. 参考资源

| 资源 | 链接/说明 |
|---|---|
| Vosk 中文模型 | https://alphacephei.com/vosk/models |
| Ollama | https://ollama.ai |
| MediaPipe | https://mediapipe.dev |
| IRremote 库 | Arduino 库管理器搜索 "IRremote" |
| ALSA 配置 | `/etc/asound.conf` 设置默认声卡 |

### C. 文档版本

| 版本 | 日期 | 变更 |
|---|---|---|
| v1.0 | 2026-07-01 | 初始版本 |
| v1.1 | 2026-07-01 | 整合 STJF USB麦克风 + 双喇叭USB音箱 + 移动电源 |
| v1.2 | 2026-07-01 | 采购改为购买或 3D 打印；移除手机 App；精简供电结构；调整实施计划 |

---

**🏠 HomeBuddy · 让家更智能，让生活更温暖 ❤️**

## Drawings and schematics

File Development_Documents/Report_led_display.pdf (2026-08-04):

# HomeBuddy 矢量图形表情显示系统 - 测试报

告

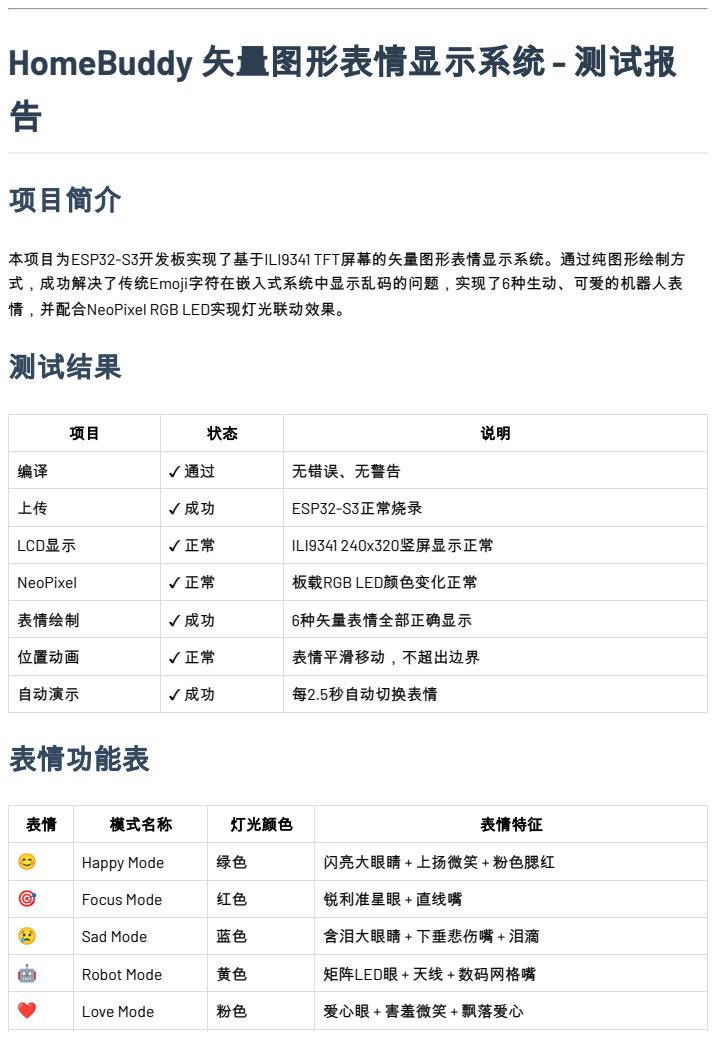
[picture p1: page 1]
项目简介; 表情功能表

本项目为ESP32-S3开发板实现了基于ILI9341 TFT屏幕的矢量图形表情显示系统。通过纯图形绘制方
式，成功解决了传统Emoji字符在嵌入式系统中显示乱码的问题，实现了6种生动、可爱的机器人表
情，并配合NeoPixel RGB LED实现灯光联动效果。
测试结果

项目 | 状态 | 说明
编译 | ✓ 通过 | 无错误、无警告
上传 | ✓ 成功 | ESP32-S3正常烧录

LCD显示 | ✓ 正常 | ILI9341 240x320竖屏显示正常

NeoPixel | ✓ 正常 | 板载RGB LED颜色变化正常
表情绘制 | ✓ 成功 | 6种矢量表情全部正确显示
位置动画 | ✓ 正常 | 表情平滑移动，不超出边界
自动演示 | ✓ 成功 | 每2.5秒自动切换表情

表情 | 模式名称 | 灯光颜色 | 表情特征
😊 | Happy Mode | 绿色 | 闪亮大眼睛 + 上扬微笑 + 粉色腮红

🎯 | Focus Mode | 红色 | 锐利准星眼 + 直线嘴
😢 | Sad Mode | 蓝色 | 含泪大眼睛 + 下垂悲伤嘴 + 泪滴

🤖 | Robot Mode | 黄色 | 矩阵LED眼 + 天线 + 数码网格嘴
❤️ | Love Mode | 粉色 | 爱心眼 + 害羞微笑 + 飘落爱心

# 项目结构

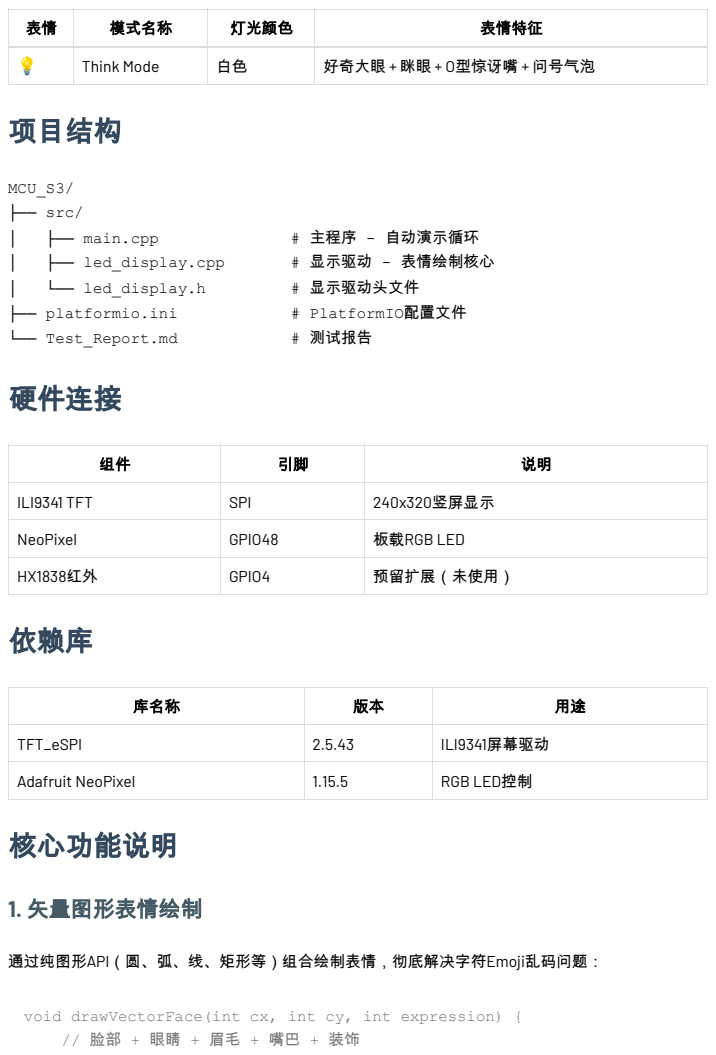
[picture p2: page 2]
MCU_S3/ ├── src/; ├── main.cpp; # 主程序 - 自动演示循环; ├── led_display.cpp; # 显示驱动 - 表情绘制核心; └── led_display.h; # 显示驱动头文件; ├── platformio.ini; # PlatformIO配置文件; └── Test_Report.md; # 测试报告; 硬件连接; 依赖库; 核心功能说明; 1. 矢量图形表情绘制

表情 | 模式名称 | 灯光颜色 | 表情特征
💡 | Think Mode | 白色 | 好奇大眼 + 眯眼 + O型惊讶嘴 + 问号气泡

ILI9341 TFT | SPI | 240x320竖屏显示

NeoPixel | GPIO48 | 板载RGB LED

HX1838红外 | GPIO4 | 预留扩展（未使用）

库名称 | 版本 | 用途

TFT_eSPI | 2.5.43 | ILI9341屏幕驱动

Adafruit NeoPixel | 1.15.5 | RGB LED控制

通过纯图形API（圆、弧、线、矩形等）组合绘制表情，彻底解决字符Emoji乱码问题：

void drawVectorFace(int cx, int cy, int expression) {

## 2. 平滑位置动画

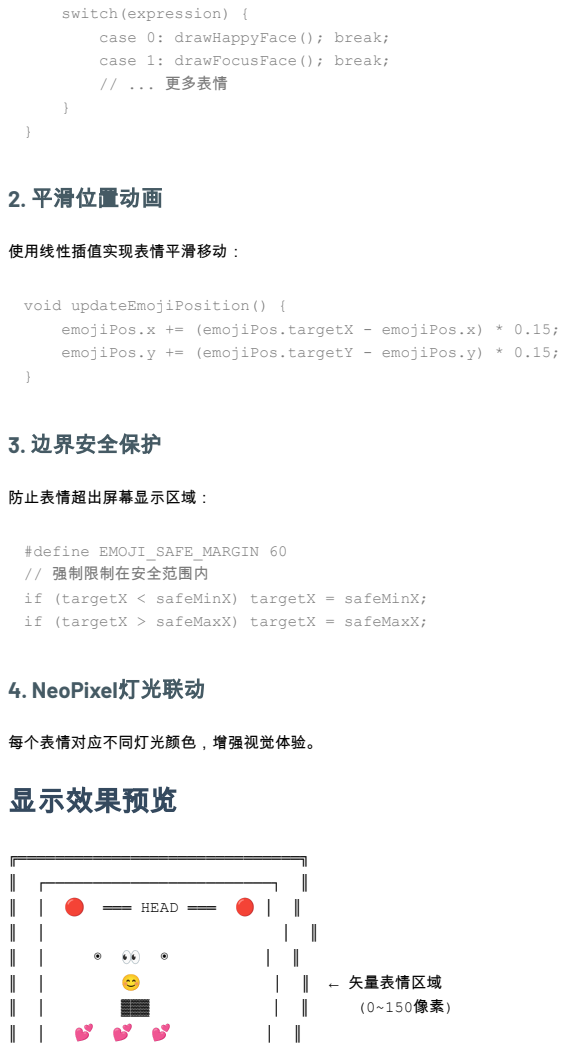
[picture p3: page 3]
使用线性插值实现表情平滑移动：; 3. 边界安全保护; 防止表情超出屏幕显示区域：; 4. NeoPixel灯光联动; 每个表情对应不同灯光颜色，增强视觉体验。 显示效果预览; ╔══════════════════════════════╗ ║ ┌────────────────────────┐ ║ ║ │ 🔴 ═══ HEAD ═══ 🔴 │ ║; │ ║ ← 矢量表情区域

switch(expression) {
case 0: drawHappyFace(); break;
case 1: drawFocusFace(); break;
// ... 更多表情

void updateEmojiPosition() {
emojiPos.x += (emojiPos.targetX - emojiPos.x) * 0.15;
emojiPos.y += (emojiPos.targetY - emojiPos.y) * 0.15;

#define EMOJI_SAFE_MARGIN 60
// 强制限制在安全范围内
if (targetX < safeMinX) targetX = safeMinX;
if (targetX > safeMaxX) targetX = safeMaxX;

# 串口输出示例

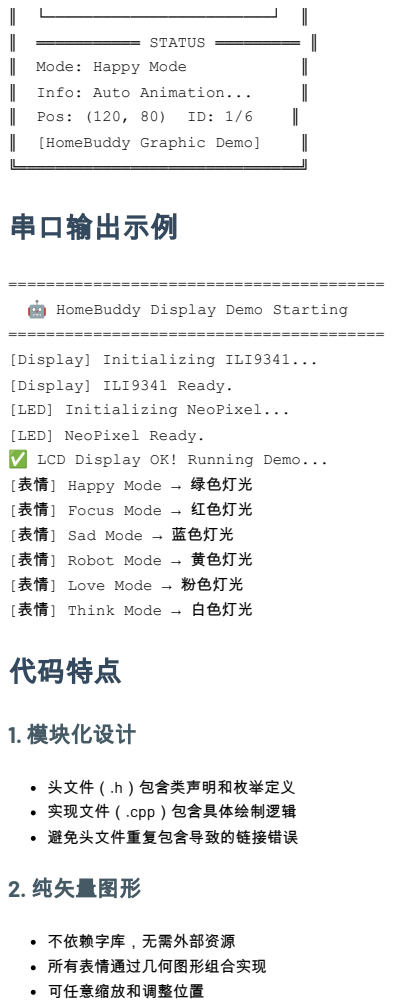
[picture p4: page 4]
║ └────────────────────────┘ ║ ║ ═══════════ STATUS ═════════ ║; ║ Mode: Happy Mode; ║ Info: Auto Animation...; ║ Pos: (120, 80) ID: 1/6; ║ [HomeBuddy Graphic Demo]; 1. 模块化设计; 不依赖字库，无需外部资源 所有表情通过几何图形组合实现 可任意缩放和调整位置

🤖 HomeBuddy Display Demo Starting
[Display] Initializing ILI9341...
[Display] ILI9341 Ready.
[LED] Initializing NeoPixel...
[LED] NeoPixel Ready.
✅ LCD Display OK! Running Demo...
[表情] Happy Mode → 绿色灯光
[表情] Focus Mode → 红色灯光
[表情] Sad Mode → 蓝色灯光
[表情] Robot Mode → 黄色灯光
[表情] Love Mode → 粉色灯光
[表情] Think Mode → 白色灯光
代码特点

头文件（.h）包含类声明和枚举定义
实现文件（.cpp）包含具体绘制逻辑
避免头文件重复包含导致的链接错误
2. 纯矢量图形

## 3. 边界安全

## 4. 易于扩展

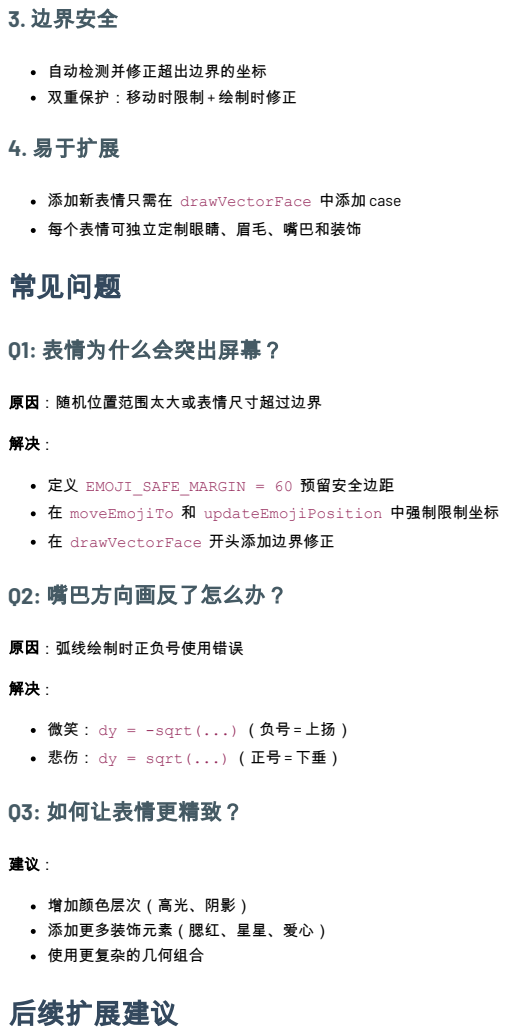
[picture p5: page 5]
Q1: 表情为什么会突出屏幕？; 原因：随机位置范围太大或表情尺寸超过边界; 原因：弧线绘制时正负号使用错误

自动检测并修正超出边界的坐标
双重保护：移动时限制 + 绘制时修正

添加新表情只需在 drawVectorFace 中添加 case
每个表情可独立定制眼睛、眉毛、嘴巴和装饰
常见问题

定义 EMOJI_SAFE_MARGIN = 60 预留安全边距
在 moveEmojiTo 和 updateEmojiPosition 中强制限制坐标
在 drawVectorFace 开头添加边界修正
Q2: 嘴巴方向画反了怎么办？

微笑： dy = -sqrt(...) （负号 = 上扬）
悲伤： dy = sqrt(...) （正号 = 下垂）
Q3: 如何让表情更精致？

增加颜色层次（高光、阴影）
添加更多装饰元素（腮红、星星、爱心）
使用更复杂的几何组合
后续扩展建议

# 测试状态

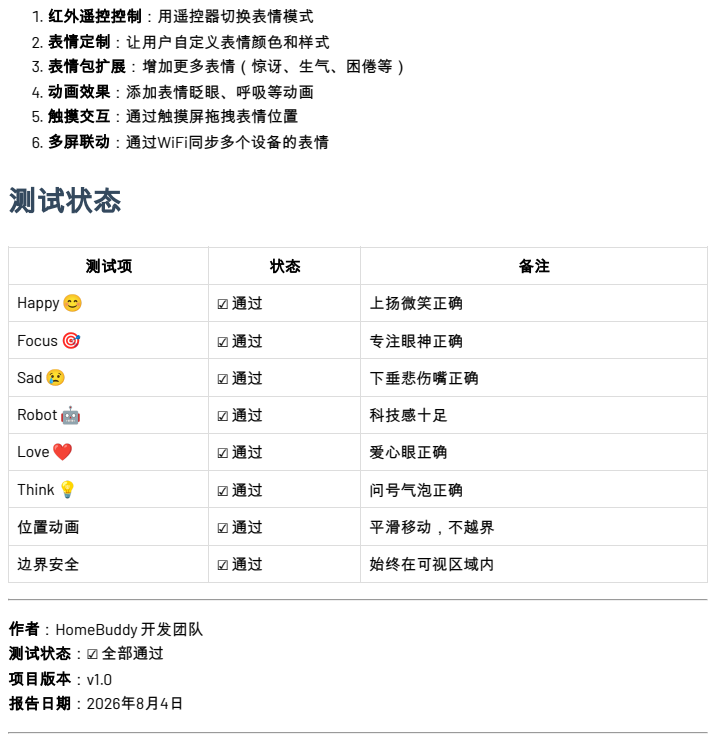
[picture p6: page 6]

1. 红外遥控控制：用遥控器切换表情模式
2. 表情定制：让用户自定义表情颜色和样式
3. 表情包扩展：增加更多表情（惊讶、生气、困倦等）
4. 动画效果：添加表情眨眼、呼吸等动画
5. 触摸交互：通过触摸屏拖拽表情位置
6. 多屏联动：通过WiFi同步多个设备的表情

测试项 | 状态 | 备注

Happy😊 | ☑ 通过 | 上扬微笑正确
Focus🎯 | ☑ 通过 | 专注眼神正确
Sad😢 | ☑ 通过 | 下垂悲伤嘴正确
Robot🤖 | ☑ 通过 | 科技感十足
Love❤️ | ☑ 通过 | 爱心眼正确
Think💡 | ☑ 通过 | 问号气泡正确
位置动画 | ☑ 通过 | 平滑移动，不越界
边界安全 | ☑ 通过 | 始终在可视区域内

作者：HomeBuddy 开发团队
测试状态：☑ 全部通过
项目版本：v1.0
报告日期：2026年8月4日

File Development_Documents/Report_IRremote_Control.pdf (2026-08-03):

# ESP32-S3 红外遥控器驱动 (IRremote Control)

# 📋项目简介

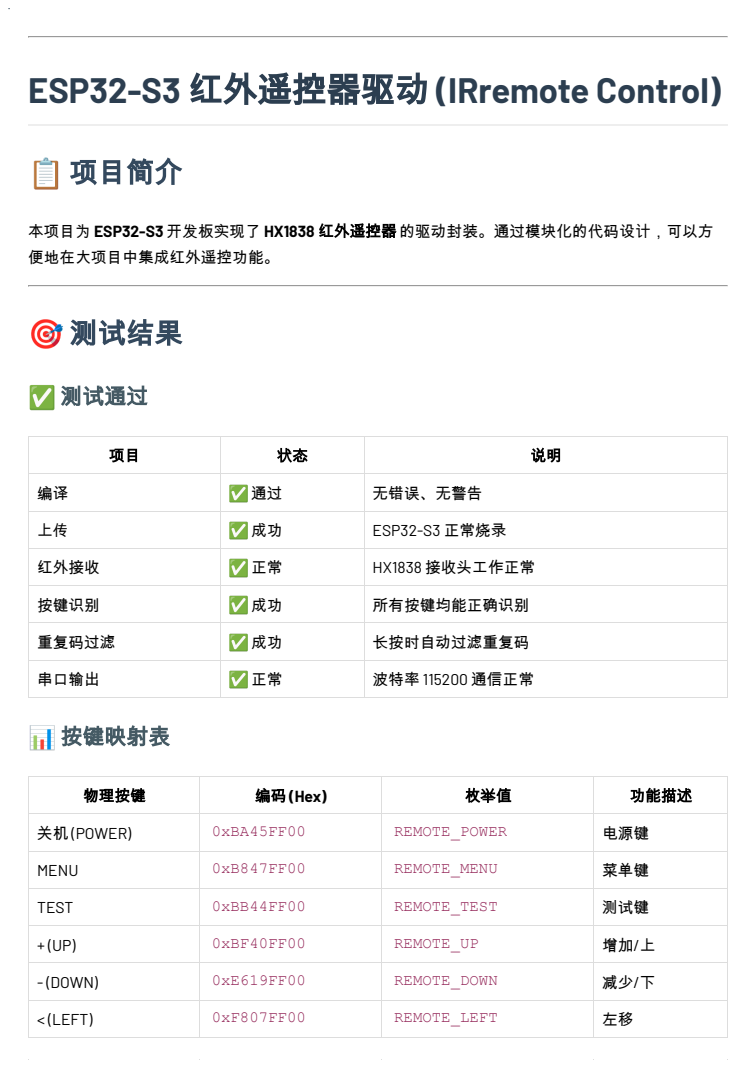
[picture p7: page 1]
✅测试通过; 📊按键映射表

本项目为 ESP32-S3 开发板实现了 HX1838 红外遥控器 的驱动封装。通过模块化的代码设计，可以方
便地在大项目中集成红外遥控功能。
🎯测试结果

编译 | ✅通过 | 无错误、无警告

上传 | ✅成功 | ESP32-S3 正常烧录
红外接收 | ✅正常 | HX1838 接收头工作正常
按键识别 | ✅成功 | 所有按键均能正确识别
重复码过滤 | ✅成功 | 长按时自动过滤重复码
串口输出 | ✅正常 | 波特率 115200 通信正常

物理按键 | 编码 (Hex) | 枚举值 | 功能描述

关机 (POWER) | 0xBA45FF00 | REMOTE_POWER | 电源键

MENU | 0xB847FF00 | REMOTE_MENU | 菜单键

TEST | 0xBB44FF00 | REMOTE_TEST | 测试键

+ (UP) | 0xBF40FF00 | REMOTE_UP | 增加/上

- (DOWN) | 0xE619FF00 | REMOTE_DOWN | 减少/下

< (LEFT) | 0xF807FF00 | REMOTE_LEFT | 左移

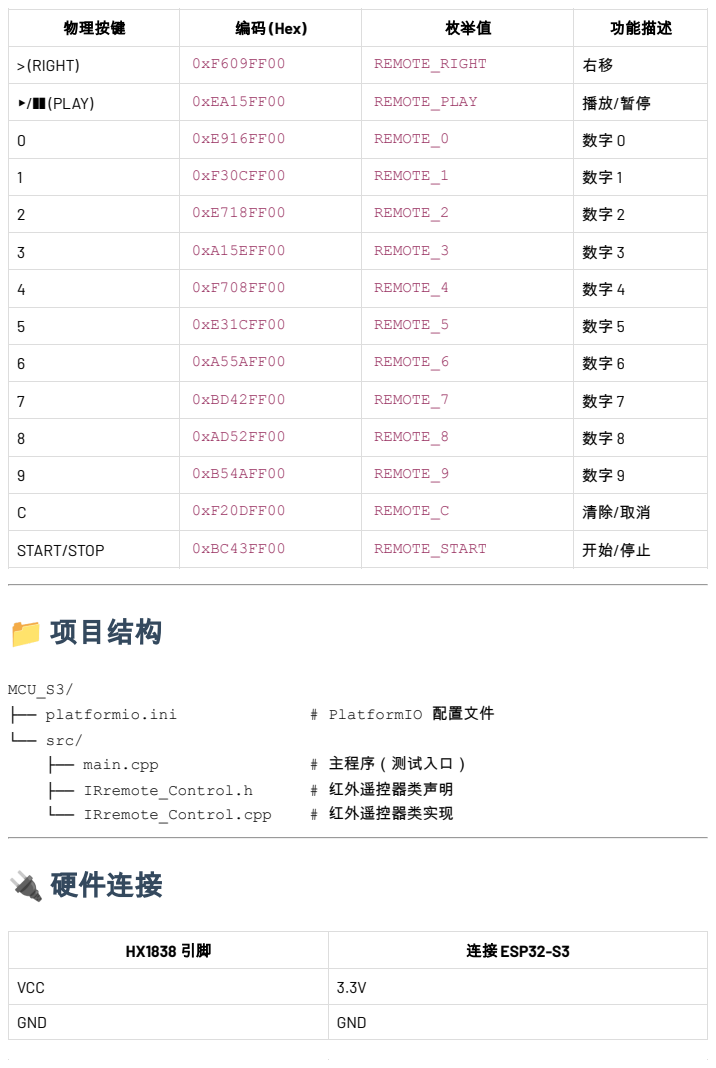
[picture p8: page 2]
📁项目结构; MCU_S3/; ├── platformio.ini; # PlatformIO 配置文件; └── src/; ├── main.cpp; # 主程序（测试入口）; ├── IRremote_Control.h; # 红外遥控器类声明; └── IRremote_Control.cpp; # 红外遥控器类实现; 🔌硬件连接

物理按键 | 编码 (Hex) | 枚举值 | 功能描述

> (RIGHT) | 0xF609FF00 | REMOTE_RIGHT | 右移

▶/❚❚ (PLAY) | 0xEA15FF00 | REMOTE_PLAY | 播放/暂停

0 | 0xE916FF00 | REMOTE_0 | 数字 0

1 | 0xF30CFF00 | REMOTE_1 | 数字 1

2 | 0xE718FF00 | REMOTE_2 | 数字 2

3 | 0xA15EFF00 | REMOTE_3 | 数字 3

4 | 0xF708FF00 | REMOTE_4 | 数字 4

5 | 0xE31CFF00 | REMOTE_5 | 数字 5

6 | 0xA55AFF00 | REMOTE_6 | 数字 6

7 | 0xBD42FF00 | REMOTE_7 | 数字 7

8 | 0xAD52FF00 | REMOTE_8 | 数字 8

9 | 0xB54AFF00 | REMOTE_9 | 数字 9

C | 0xF20DFF00 | REMOTE_C | 清除/取消

START/STOP | 0xBC43FF00 | REMOTE_START | 开始/停止

HX1838 引脚 | 连接 ESP32-S3

VCC | 3.3V
GND | GND

# 📦依赖库

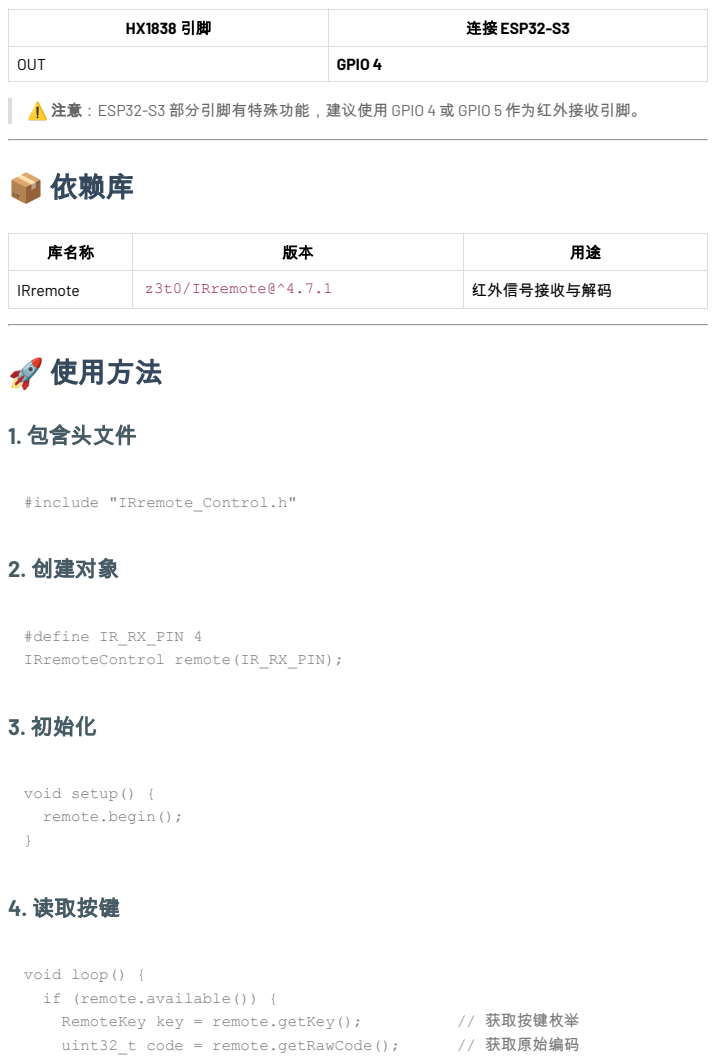
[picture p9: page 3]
🚀使用方法; 1. 包含头文件; #include "IRremote_Control.h"; 2. 创建对象; #define IR_RX_PIN 4 IRremoteControl remote(IR_RX_PIN);; 3. 初始化; void setup() { remote.begin();; 4. 读取按键; RemoteKey key = remote.getKey();; // 获取按键枚举; uint32_t code = remote.getRawCode();; // 获取原始编码

HX1838 引脚 | 连接 ESP32-S3

OUT | GPIO 4

⚠️注意：ESP32-S3 部分引脚有特殊功能，建议使用 GPIO 4 或 GPIO 5 作为红外接收引脚。

库名称 | 版本 | 用途

IRremote | z3t0/IRremote@^4.7.1 | 红外信号接收与解码

void loop() {
if (remote.available()) {

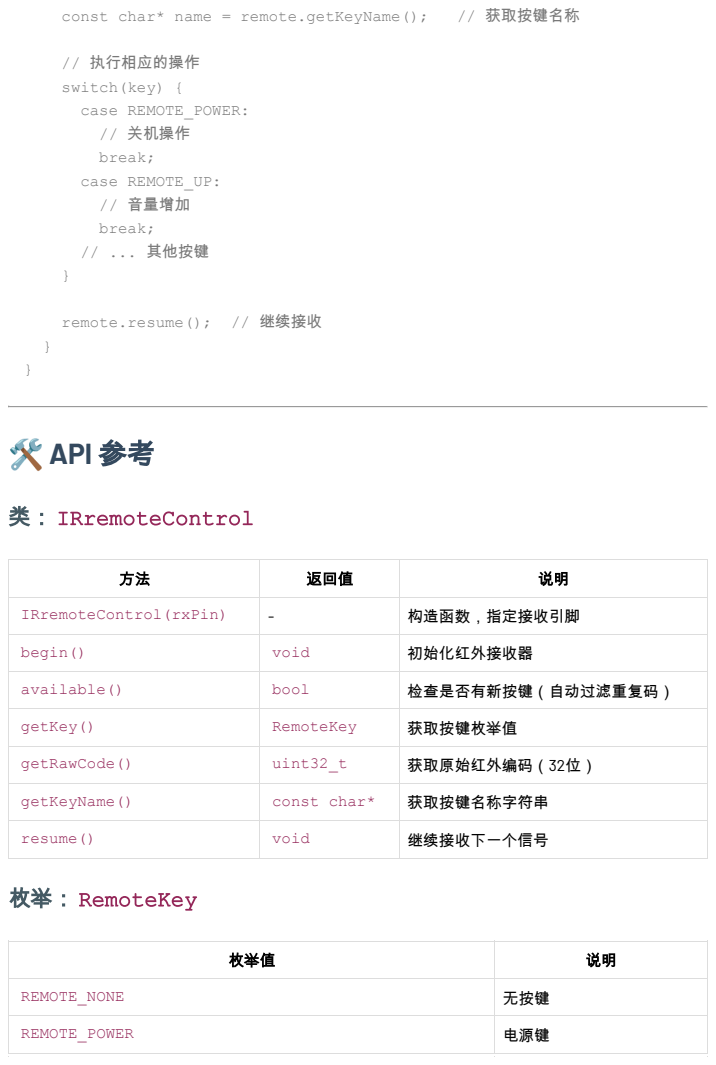
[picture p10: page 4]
const char* name = remote.getKeyName();; // 获取按键名称; // 执行相应的操作; switch(key) { case REMOTE_POWER: // 关机操作; break; case REMOTE_UP: // 音量增加; break; // ... 其他按键; remote.resume(); // 继续接收; ️API 参考; 类： IRremoteControl; 枚举： RemoteKey

方法 | 返回值 | 说明

IRremoteControl(rxPin) | - | 构造函数，指定接收引脚

begin() | void | 初始化红外接收器
available() | bool | 检查是否有新按键（自动过滤重复码）

getKey() | RemoteKey | 获取按键枚举值

getRawCode() | uint32_t | 获取原始红外编码（32位）

getKeyName() | const char* | 获取按键名称字符串

resume() | void | 继续接收下一个信号

枚举值 | 说明

REMOTE_NONE | 无按键

REMOTE_POWER | 电源键

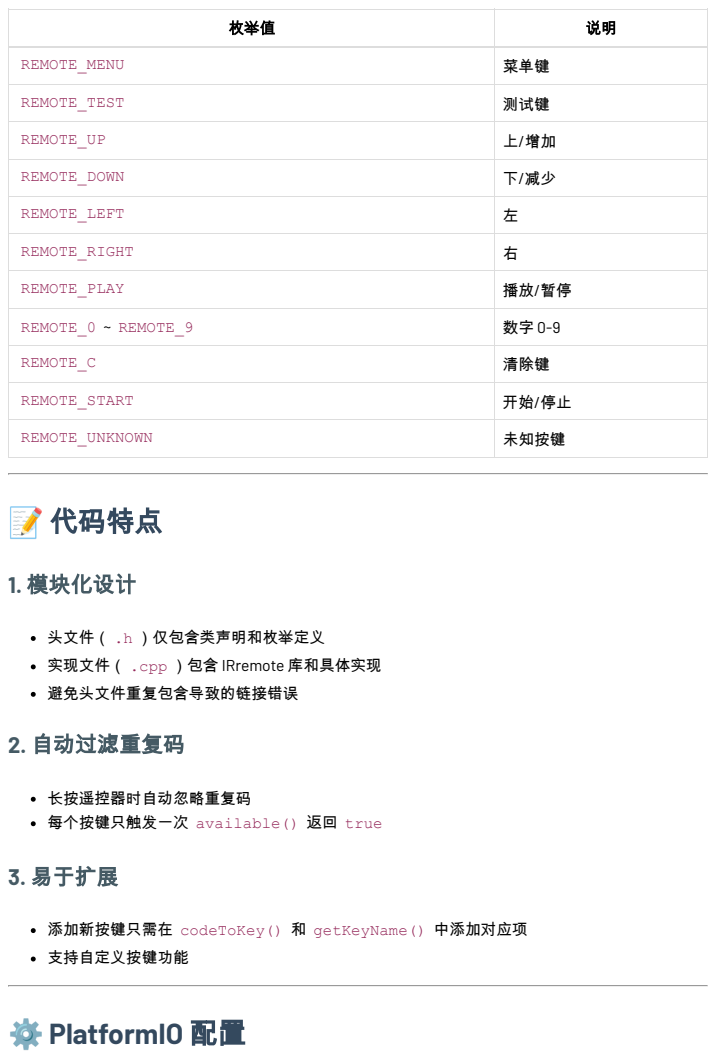
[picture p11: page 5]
📝代码特点; 1. 模块化设计; ⚙️PlatformIO 配置

枚举值 | 说明

REMOTE_MENU | 菜单键

REMOTE_TEST | 测试键

REMOTE_UP | 上/增加

REMOTE_DOWN | 下/减少

REMOTE_LEFT | 左

REMOTE_RIGHT | 右

REMOTE_PLAY | 播放/暂停

REMOTE_0 ~ REMOTE_9 | 数字 0-9

REMOTE_C | 清除键

REMOTE_START | 开始/停止

REMOTE_UNKNOWN | 未知按键

头文件（ .h ）仅包含类声明和枚举定义
实现文件（ .cpp ）包含 IRremote 库和具体实现
避免头文件重复包含导致的链接错误
2. 自动过滤重复码

长按遥控器时自动忽略重复码
每个按键只触发一次 available() 返回 true
3. 易于扩展

添加新按键只需在 codeToKey() 和 getKeyName() 中添加对应项
支持自定义按键功能

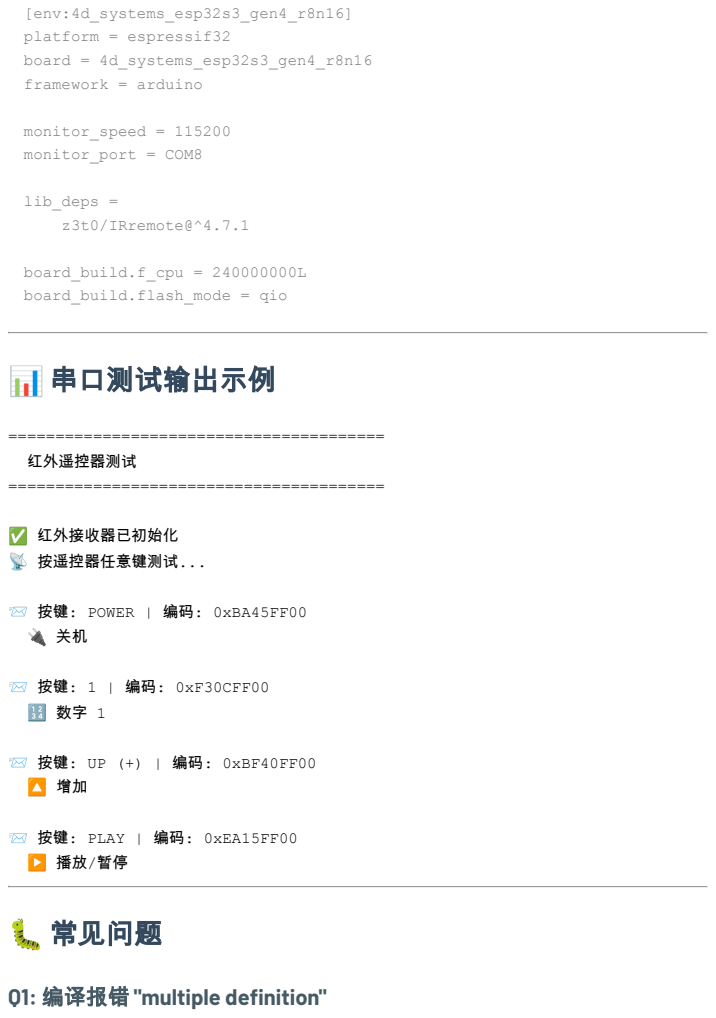
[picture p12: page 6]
[env:4d_systems_esp32s3_gen4_r8n16] platform = espressif32 board = 4d_systems_esp32s3_gen4_r8n16 framework = arduino; monitor_speed = 115200 monitor_port = COM8; lib_deps = z3t0/IRremote@^4.7.1; board_build.f_cpu = 240000000L board_build.flash_mode = qio; 📊串口测试输出示例; ======================================== 红外遥控器测试; ✅ 红外接收器已初始化 📡 按遥控器任意键测试...; 📨 按键: 1 | 编码: 0xF30CFF00 🔢 数字 1

📨 按键: POWER | 编码: 0xBA45FF00

📨 按键: UP (+) | 编码: 0xBF40FF00

📨 按键: PLAY | 编码: 0xEA15FF00
🐛常见问题

Q1: 编译报错 "multiple definition"

## Q2: 串口没有输出

1. ESP32-S3 是否正确连接 USB 2. 波特率是否设置为 115200 3. 是否需要按 RESET 键; Q3: 红外接收不工作; 这是正常现象，代码已自动过滤重复码。; 📌后续扩展建议; 本项目仅供学习和参考使用。

原因：IRremote 库被多次包含

解决：确保 .h 文件中不包含 IRremote.h ，只在 .cpp 中包含

1. HX1838 OUT 引脚是否连接到 GPIO 4
2. HX1838 VCC 是否接 3.3V（不要接 5V）
3. 遥控器电池是否有电
4. 是否按住遥控器按键并靠近接收头
Q4: 长按按键出现多个"未知"

1. LED 控制：用数字键控制不同颜色的 LED
2. 电机控制：用方向键控制舵机或步进电机
3. 智能家居：通过 WiFi 发送 MQTT 指令
4. OLED 显示：在屏幕上显示当前按下的按键
5. 音量控制：用 +/- 键控制音量
📄许可证

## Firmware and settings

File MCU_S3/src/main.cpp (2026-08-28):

#include <Arduino.h>
#include "ultrasonic.h"

// 定义引脚
#define TRIG_PIN  5
#define ECHO_PIN  6

// 创建超声波对象
Ultrasonic ultrasonic(TRIG_PIN, ECHO_PIN);

void setup() {
    Serial.begin(115200);
    ultrasonic.begin();
    Serial.println("超声波传感器已启动");
    
    // 可选：自定义阈值
    // ultrasonic.setThresholds(15.0f, 45.0f); // 改成 15cm 紧急，45cm 安全
}

void loop() {
    // 读取距离
    float dist = ultrasonic.getDistance();
    
    if (dist > 0) {
        // 方法1：用枚举判断
        switch (ultrasonic.getStatus()) {
            case STATUS_EMERGENCY:
                Serial.printf("🚨 紧急！%.2f cm，立即刹车！\n", dist);
                // 这里写你的刹车逻辑
                break;
            case STATUS_SAFE:
                Serial.printf("✅ 安全！%.2f cm，正常行驶\n", dist);
                break;
            case STATUS_FAR:
                Serial.printf("📡 较远！%.2f cm，可加速\n", dist);
                break;
            default:
                break;
        }

        // 方法2：直接用布尔函数判断（更简洁）
        if (ultrasonic.isEmergency()) {
            // 紧急处理
            Serial.println("⚠️ 紧急制动！");
        } else if (ultrasonic.isSafe()) {
            // 安全处理
        } else if (ultrasonic.isFar()) {
            // 远距离处理
        }
    } else {
        Serial.println("⚠️ 读数无效，请检查传感器");
    }

    delay(300);
}

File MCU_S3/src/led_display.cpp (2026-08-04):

// ============================================================
// led_display.cpp - HomeBuddy 矢量图形表情版 (修复嘴巴方向)
// ============================================================

#include "led_display.h"

#ifndef TFT_GREY
#define TFT_GREY 0x8410
#endif

// ---------- 板载 NeoPixel ----------
#define NEOPIXEL_PIN   48
#define NEOPIXEL_COUNT 1

// ---------- 全局对象 ----------
TFT_eSPI tft = TFT_eSPI();
Adafruit_NeoPixel pixel(NEOPIXEL_COUNT, NEOPIXEL_PIN, NEO_GRB + NEO_KHZ800);

// 状态管理
EmojiPosition emojiPos;
int currentEmoji = 0;

const char* statusMessages[] = {
    "Happy Mode",
    "Focus Mode", 
    "Sad Mode",
    "Robot Mode",
    "Love Mode",
    "Think Mode"
};

// ============================================================
// 初始化
// ============================================================

void initDisplay() {
    Serial.println("[Display] Initializing ILI9341...");
    tft.begin();
    tft.setRotation(0);
    
    tft.fillScreen(TFT_BLACK);
    tft.setTextColor(TFT_WHITE, TFT_BLACK);
    tft.setTextSize(2);
    tft.setCursor(30, 130);
    tft.println("HomeBuddy");
    tft.setCursor(50, 160);
    tft.setTextSize(1);
    tft.println("Loading...");
    
    Serial.println("[Display] ILI9341 Ready.");
}

void initNeoPixel() {
    Serial.println("[LED] Initializing NeoPixel...");
    pixel.begin();
    pixel.setBrightness(30);
    pixel.fill(pixel.Color(0, 255, 0));
    pixel.show();
    Serial.println("[LED] NeoPixel Ready.");
}

void initLED() {
    initDisplay();
    initNeoPixel();
}

void initEmojiPosition() {
    // 初始位置在屏幕中央安全区域
    emojiPos.x = 120.0;
    emojiPos.y = 80.0;
    emojiPos.targetX = 120.0;
    emojiPos.targetY = 80.0;
    
    // 设置安全范围
    emojiPos.minX = EMOJI_SAFE_MARGIN;
    emojiPos.maxX = TFT_WIDTH - EMOJI_SAFE_MARGIN;
    emojiPos.minY = EMOJI_SAFE_MARGIN + 10;
    emojiPos.maxY = 150 - EMOJI_SAFE_MARGIN;
}

// ============================================================
// 位置动画逻辑 - 带边界保护
// ============================================================

void moveEmojiTo(int targetX, int targetY) {
    // 强制限制在安全范围内
    int safeMinX = EMOJI_SAFE_MARGIN;
    int safeMaxX = TFT_WIDTH - EMOJI_SAFE_MARGIN;
    int safeMinY = EMOJI_SAFE_MARGIN + 10;
    int safeMaxY = 150 - EMOJI_SAFE_MARGIN;
    
    if (targetX < safeMinX) targetX = safeMinX;
    if (targetX > safeMaxX) targetX = safeMaxX;
    if (targetY < safeMinY) targetY = safeMinY;
    if (targetY > safeMaxY) targetY = safeMaxY;
    
    emojiPos.targetX = targetX;
    emojiPos.targetY = targetY;
}

void updateEmojiPosition() {
    emojiPos.x += (emojiPos.targetX - emojiPos.x) * 0.15;
    emojiPos.y += (emojiPos.targetY - emojiPos.y) * 0.15;
    
    // 确保插值过程中也不会超出边界
    int safeMinX = EMOJI_SAFE_MARGIN;
    int safeMaxX = TFT_WIDTH - EMOJI_SAFE_MARGIN;
    int safeMinY = EMOJI_SAFE_MARGIN + 10;
    int safeMaxY = 150 - EMOJI_SAFE_MARGIN;
    
    if (emojiPos.x < safeMinX) emojiPos.x = safeMinX;
    if (emojiPos.x > safeMaxX) emojiPos.x = safeMaxX;
    if (emojiPos.y < safeMinY) emojiPos.y = safeMinY;
    if (emojiPos.y > safeMaxY) emojiPos.y = safeMaxY;
}

// ============================================================
// 🎨 辅助绘制函数（表情组件）
// ============================================================

// ---------- 闪亮的大眼睛 ----------
void drawShinyEye(int x, int y, int r, uint16_t irisColor, uint16_t highlightColor) {
    // 眼白
    tft.fillCircle(x, y, r, TFT_WHITE);
    tft.drawCircle(x, y, r, 0x7BEF);
    
    // 虹膜
    tft.fillCircle(x + 3, y + 2, r * 0.6, irisColor);
    tft.fillCircle(x + 3, y + 2, r * 0.35, 0x0000); // 瞳孔
    
    // 高光（双高光更真实）
    tft.fillCircle(x - 4, y - 5, r * 0.25, highlightColor);
    tft.fillCircle(x - 6, y - 7, r * 0.12, highlightColor);
    
    // 下眼睑（用弧线）
    for (int angle = 180; angle <= 360; angle += 5) {
        float rad = angle * 3.14159 / 180;
        int px = x + (r * 0.7) * cos(rad);
        int py = y + r * 0.3 + (r * 0.5) * sin(rad);
        tft.drawPixel(px, py, TFT_DARKGREY);
    }
}

// ---------- 眉毛 ----------
void drawEyebrow(int x, int y, int length, int slope, uint16_t color) {
    int endY = y + slope * 6;
    for (int i = -2; i <= 2; i++) {
        tft.drawLine(x - length/2, y + i, x + length/2, endY + i, color);
    }
}

// ---------- 微笑嘴（弧形上扬）- 修复版 ----------
void drawHappyMouth(int x, int y, int width) {
    int r = width / 2;
    // 微笑：弧线中心下压，形成向上开口的笑脸
    for (int i = -r; i <= r; i++) {
        int dy = sqrt(r * r - i * i) * 0.6;
        for (int j = 0; j < 3; j++) {
            tft.drawPixel(x + i, y + dy + j, TFT_WHITE);
        }
    }
    // 嘴巴内部（红色）- 稍微下移一点
    tft.fillRect(x - r * 0.6, y + 4, r * 1.2, 3, TFT_RED);
}

// ---------- 锐利专注眼 ----------
void drawSharpEye(int x, int y, int r, uint16_t color) {
    tft.fillCircle(x, y, r, TFT_WHITE);
    tft.fillCircle(x + 2, y, r * 0.55, color);
    tft.fillCircle(x + 2, y, r * 0.3, 0x0000);
    tft.fillCircle(x - 3, y - 4, 3, TFT_WHITE);
    
    tft.drawLine(x - r - 6, y - 4, x - r, y, TFT_BLACK);
    tft.drawLine(x + r + 6, y - 4, x + r, y, TFT_BLACK);
}

// ---------- 直线嘴 ----------
void drawStraightMouth(int x, int y, int width, uint16_t color) {
    tft.fillRoundRect(x - width/2, y - 2, width, 4, 2, color);
}

// ---------- 含泪眼 ----------
void drawTearfulEye(int x, int y, int r) {
    tft.fillCircle(x, y, r, 0x7BEF);
    tft.fillCircle(x + 2, y + 2, r * 0.5, TFT_BLUE);
    tft.fillCircle(x + 2, y + 2, r * 0.3, 0x0000);
    tft.fillCircle(x - 3, y - 4, 3, TFT_WHITE);
    
    tft.fillCircle(x - 2, y + r + 2, 3, TFT_CYAN);
    tft.fillCircle(x + 1, y + r + 5, 2, TFT_CYAN);
}

// ---------- 悲伤嘴（倒弧下垂）- 修复版 ----------
void drawSadMouth(int x, int y, int width) {
    int r = width / 2;
    // 悲伤：弧线中心上抬，形成向下开口的哭脸
    for (int i = -r; i <= r; i++) {
        int dy = -sqrt(r * r - i * i) * 0.5;
        tft.drawPixel(x + i, y + dy, TFT_WHITE);
        tft.drawPixel(x + i, y + dy + 1, TFT_WHITE);
    }
}

// ---------- 泪滴 ----------
void drawTeardrop(int x, int y) {
    tft.fillCircle(x, y, 4, TFT_CYAN);
    tft.fillCircle(x, y + 2, 3, 0x7BEF);
    tft.drawLine(x - 2, y + 4, x - 1, y + 8, TFT_CYAN);
    tft.drawLine(x + 2, y + 4, x + 1, y + 8, TFT_CYAN);
}

// ---------- 机器人眼 ----------
void drawRobotEye(int x, int y, int size) {
    tft.drawRoundRect(x - size, y - size * 0.7, size * 2, size * 1.4, 4, TFT_CYAN);
    tft.fillRoundRect(x - size + 2, y - size * 0.7 + 2, size * 2 - 4, size * 1.4 - 4, 3, TFT_BLACK);
    
    int ledSize = 4;
    for (int row = -1; row <= 1; row++) {
        for (int col = -2; col <= 2; col++) {
            if (row == 0 || col == 0) {
                tft.fillCircle(x + col * 6, y + row * 6, ledSize, TFT_GREEN);
                tft.fillCircle(x + col * 6, y + row * 6, ledSize - 1, 0x07E0);
            }
        }
    }
}

// ---------- 天线 ----------
void drawAntenna(int x, int y) {
    tft.drawLine(x, y, x, y - 15, TFT_CYAN);
    tft.fillCircle(x, y - 15, 4, TFT_RED);
    tft.fillCircle(x, y - 15, 2, 0xFC00);
}
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

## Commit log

2026-07-01 Revise README for HomeBuddy project to v1.2
    Updated the README to version 1.2, including procurement methods, power structure simplification, removal of mobile app control, and adjustment of implementation plans.
2026-07-01 Update print statement from 'Hello' to 'Goodbye'
2026-07-04 Initial project structure: Development_Documents, ESP32, Raspberry_Pi
2026-07-04 Add Raspberry_Pi/main.py
2026-08-03 Add Function led_display
    [Kicad_ESP32_MCU.kicad_pcb, Kicad_ESP32_MCU.kicad_sch]
2026-08-10 Finish uart_comm.cpp/h
    [Kicad_ESP32_MCU.kicad_pcb, Kicad_ESP32_MCU.kicad_sch]
2026-08-28 Add uart comm
